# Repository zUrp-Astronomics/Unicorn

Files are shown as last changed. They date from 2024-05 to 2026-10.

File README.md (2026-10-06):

<!-- zurp-readme-header:begin — paste this block once, never again: the poster and the badges update themselves at each build of the site — do not edit it -->
<div align="center">

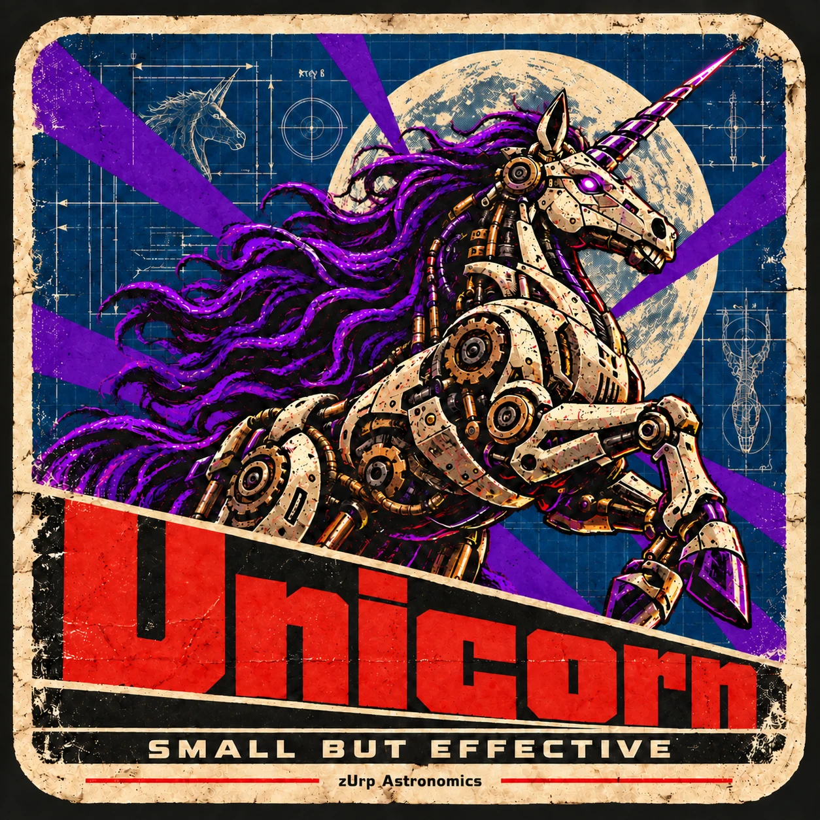
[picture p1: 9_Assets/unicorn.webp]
zUrp Astronomics product poster




</div>

<!-- zurp-readme-header:end -->

# Unicorn — Mount Control Station

# ⚠ Work in Progress — NOT VALIDATED — don't build it ⚠

### A small but efficient controller board for astronomical mounts, featuring TeenAstro Redux

Unicorn is the author's own interpretation of TeenAstro. The files keep the names of the parent
project (`TeenAstro_Redux…`); Unicorn is the zUrp name given to this build.

Visit the main project wiki on [groups.io](https://groups.io/g/TeenAstro/wiki).

The firmware is available on the [TeenAstro GitHub](https://github.com/charleslemaire0/TeenAstro) (support in progress).

## Project details

The source project can be found on [OSHWLab](https://oshwlab.com/lordzurp/teenastro-redux).

### Main board: TeenAstro Redux

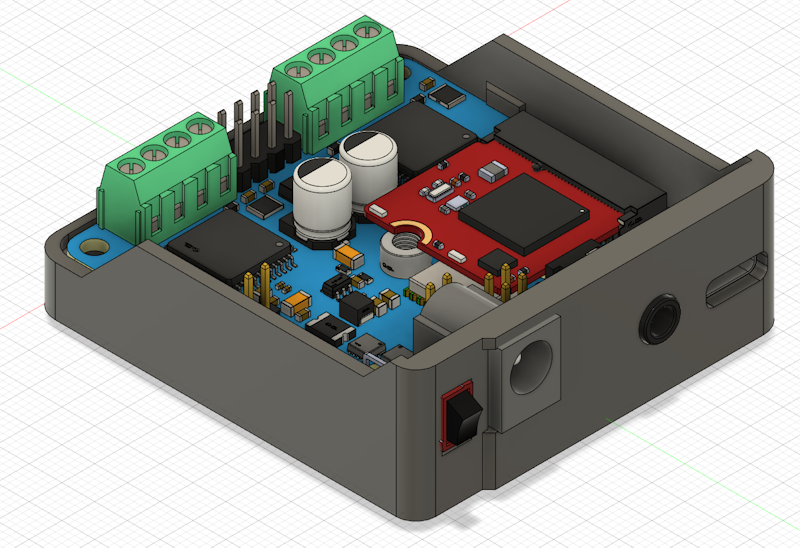
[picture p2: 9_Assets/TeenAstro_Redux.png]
Main board 3D view


#### Specs

* 56 × 52 mm form factor, 60 × 56 × 20 mm 3D-printed case
* 12 to 25 V power input, 3 A max
* Power protection (resettable fuse + reverse polarity)
* ESD protection on the USB and SHC ports
* USB-C connector
* Teensy 4.0 MicroMod
* TMC2660 stepper drivers
* Integrated GNSS
* Encoder support
* No ST4 port

#### PCB views

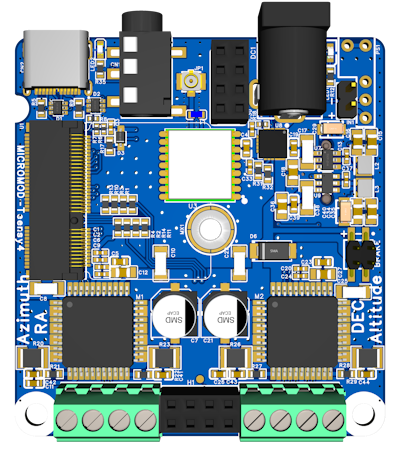
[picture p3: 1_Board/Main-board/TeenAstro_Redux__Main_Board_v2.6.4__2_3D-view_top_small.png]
Main board 3D view, top
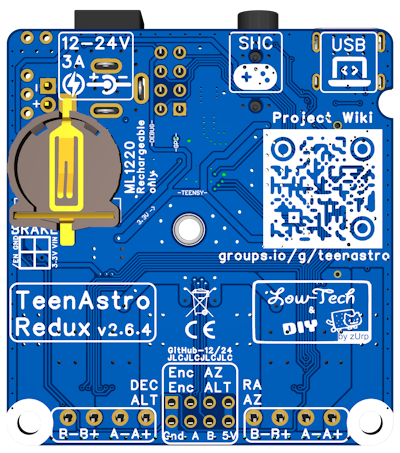
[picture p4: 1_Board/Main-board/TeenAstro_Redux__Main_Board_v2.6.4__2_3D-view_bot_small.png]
Main board 3D view, bottom
 

### Smart Hand Controller (SHC)

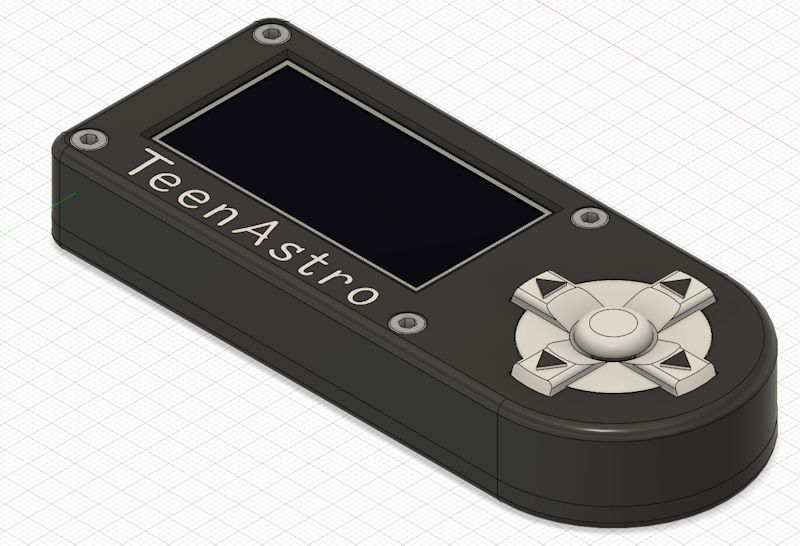
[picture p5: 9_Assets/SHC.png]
SHC 3D view


#### Specs

* 125 × 50 × 20 mm 3D-printed case
* ESP8266 (Wemos D1 mini)
* 2.42" OLED display
* Tactile switches with D-pad style buttons
* Selectable 3.3 V or 5 V power input
* Link through a 4-pin 3.5 mm headphone jack
* No focuser control (planned for later)

#### PCB views

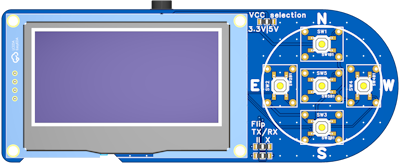
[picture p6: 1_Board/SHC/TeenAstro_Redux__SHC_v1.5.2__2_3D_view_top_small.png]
SHC 3D view, top
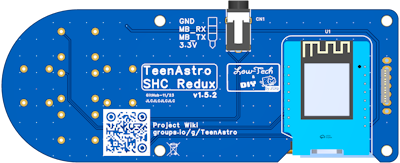
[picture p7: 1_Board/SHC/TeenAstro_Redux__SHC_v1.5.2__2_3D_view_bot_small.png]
SHC 3D view, bottom
 

### Brake module

#### PCB views

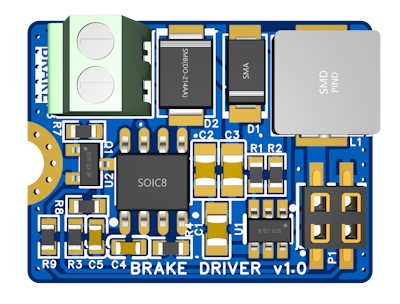
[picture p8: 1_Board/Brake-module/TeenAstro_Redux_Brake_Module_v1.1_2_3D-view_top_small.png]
Brake module 3D view, top
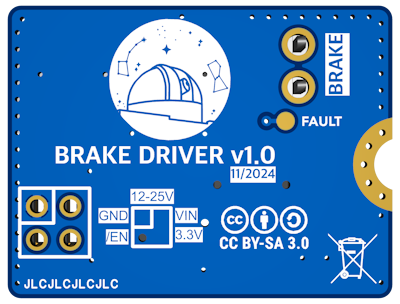
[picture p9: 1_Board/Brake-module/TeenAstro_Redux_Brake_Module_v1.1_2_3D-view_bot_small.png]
Brake module 3D view, bottom
 

## Build instructions

### The fancy way: JLCPCB prototyping service

Open the OSHWLab project in the editor, click "Order PCB", wait a week or two, and enjoy!

The BOM is tuned to minimise assembly costs, so some through-hole components are excluded from
factory assembly: you need to order them and solder them yourself. The good news is that you can
customise the connectors or reuse your own component stock ;)

The through-hole parts are listed in the BOM file, with the "Add into BOM" option set to "No".

### The hard way: do it all yourself

All the necessary files are available in `1_Board/`: complete BOM, Gerber files and pick-and-place.
Choose your PCB manufacturer, order the parts yourself, and level up your soldering skills with a
fully hand-assembled board. Be aware that some components are very small or fine-pitch: manual
assembly should be reserved for advanced, skilled users.

### 3D case

3D models are available to print the cases. The source files (Fusion 360 and STEP, in
`2_Hardware/`) let you customise the cases, while the .3MF files (in `3_3D-Models/`) are ready to
slice and print.

## Repository layout

| folder | contents |
|---|---|
| `0_Datasheets/` | component datasheets |
| `1_Board/` | board manufacturing files: schematics, views, Gerber, BoM, PnP; several boards: one subfolder per board |
| `2_Hardware/` | off-board mechanics: enclosure, parts (STEP), mechanical bill of materials |
| `3_3D-Models/` | ready-to-print files (3MF, STL) |
| `4_Firmware/` | firmware: sources, build, tests |
| `5_App/` | PC / phone applications, configuration tools |
| `9_Assets/` | images for the README and docs; `zurp.yml` showcase sheet and poster, read by the site |

A folder with no purpose for the project is absent.

## Licenses

- Software: GPL-3.0, see [`LICENSE`](LICENSE).
- Hardware: Open Community License (OCL v1.1), see [`LICENSE-HARDWARE`](LICENSE-HARDWARE).

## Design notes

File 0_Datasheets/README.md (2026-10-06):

# 0_Datasheets

Les datasheets des composants utilisés (PDF du fabricant, nom d'origine).

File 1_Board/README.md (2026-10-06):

# 1_Board

Les fichiers de fabrication de la carte, tels que les sort l'outil de CAO.

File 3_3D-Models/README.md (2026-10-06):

# 3_3D-Models

Les fichiers prêts à imprimer, tirés de `2_Hardware/`.

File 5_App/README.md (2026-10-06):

# 5_App

Les applications qui parlent au produit, dont l'outil de configuration TeenAstroConfig.

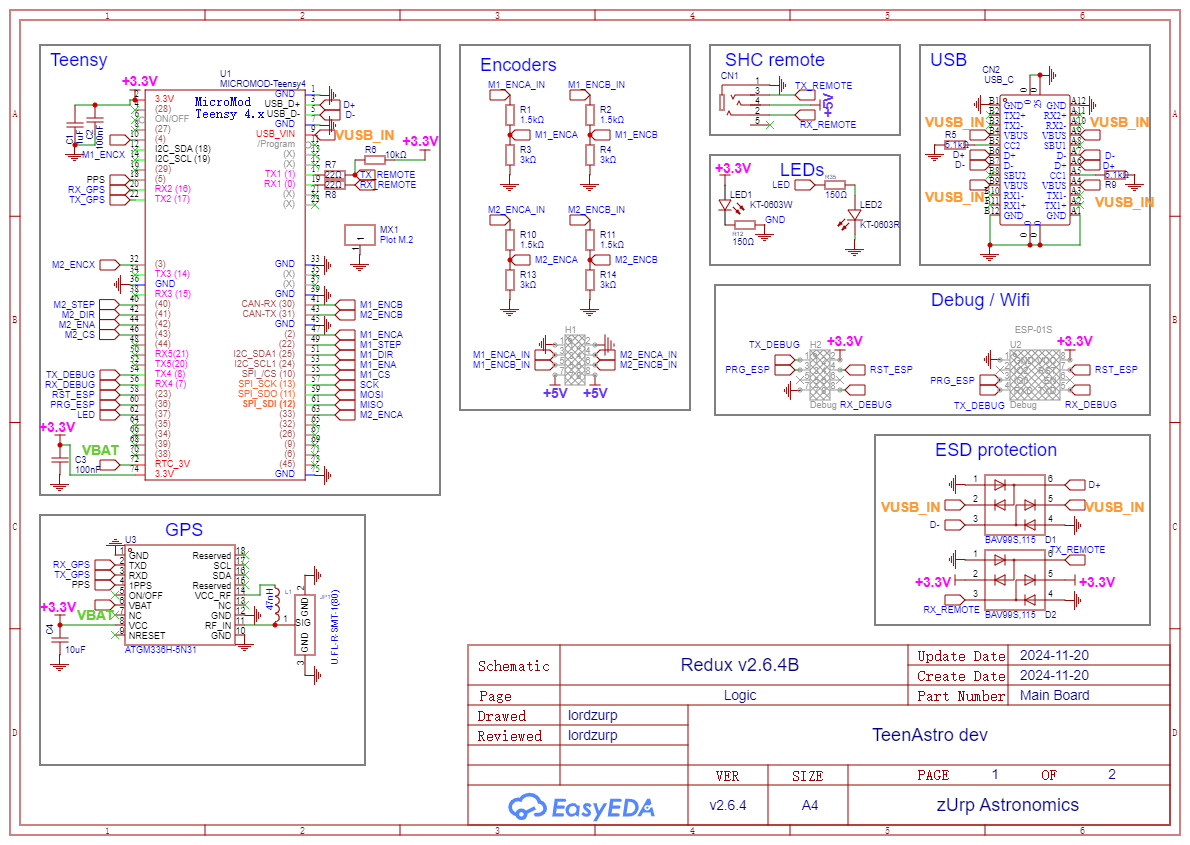
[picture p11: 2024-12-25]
1_Board/Main-board/TeenAstro_Redux__Main_Board_v2.6.4__1_schematics_logic.png

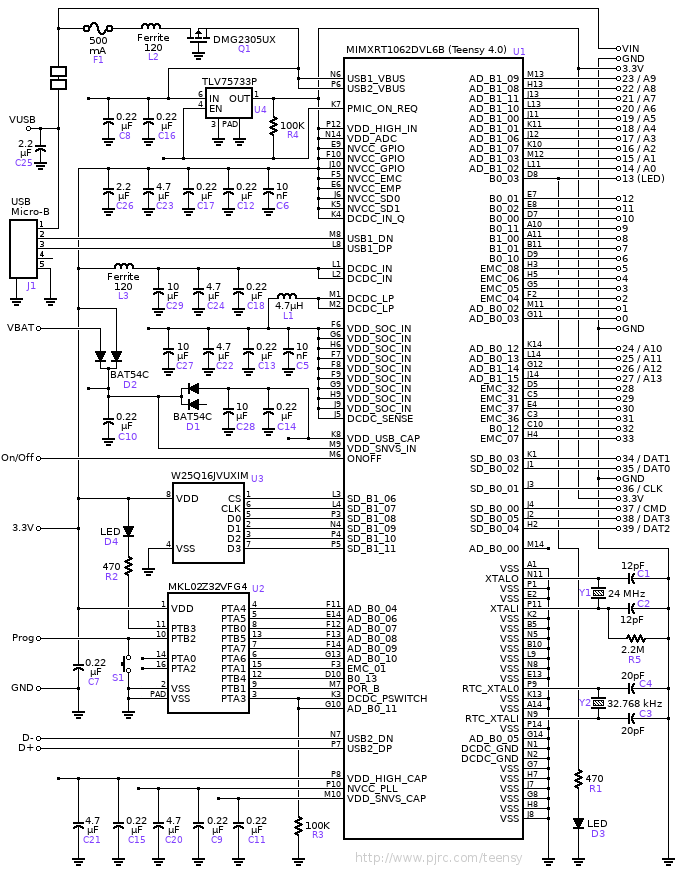
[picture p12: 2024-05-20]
0_Datasheets/#2_MCU/Teensy_4.0_schematic.png

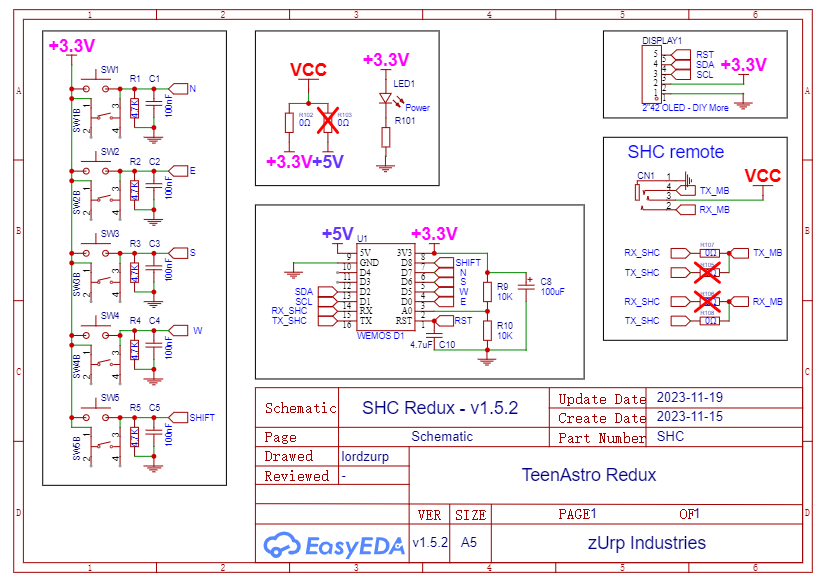
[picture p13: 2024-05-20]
1_Board/SHC/TeenAstro_Redux__SHC_v1.5.2__1_Schematics.png

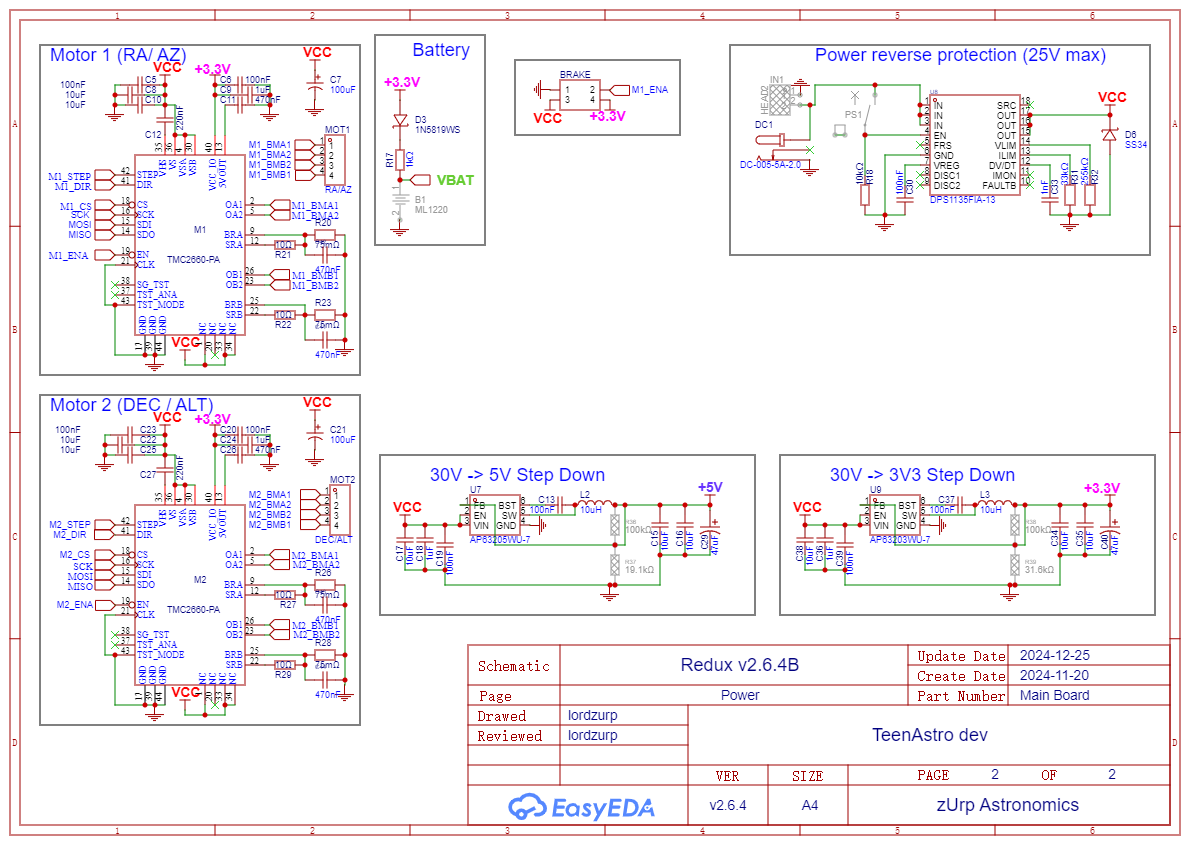
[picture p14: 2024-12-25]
1_Board/Main-board/TeenAstro_Redux__Main_Board_v2.6.4__1_schematics_power.png

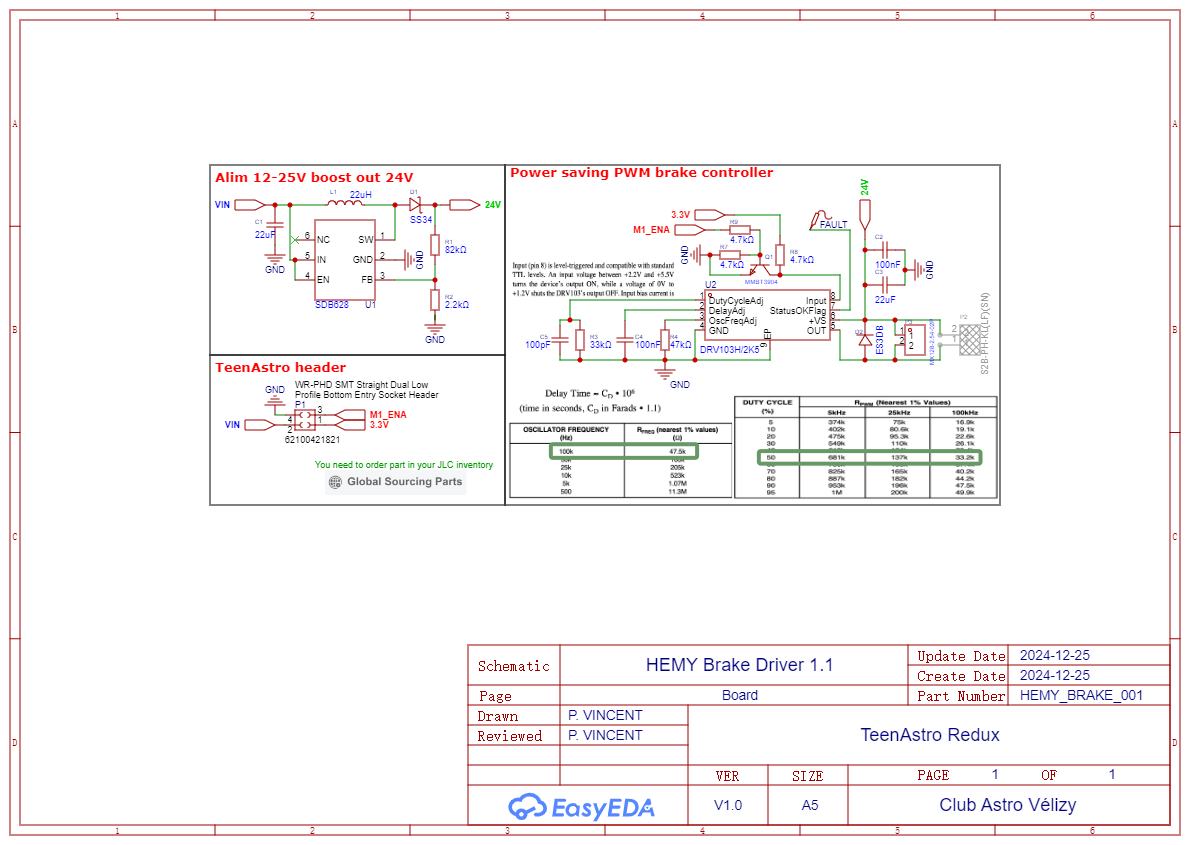
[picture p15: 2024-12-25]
1_Board/Brake-module/TeenAstro_Redux_Brake_Module_v1.1_1_schematics.png

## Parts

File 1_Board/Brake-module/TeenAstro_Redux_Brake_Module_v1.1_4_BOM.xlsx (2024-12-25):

No. | Quantity | Device | Designator | Footprint | Value | Manufacturer Part | Manufacturer | Supplier Part | Supplier | Add into BOM | Name | Primary Category | Secondary Category | JLCPCB Stock | JLCPCB Price | JLCPCB Part Class
1 | 2 | CGA0805X5R226M350MT | C1,C3 | C0805 | 22uF | CGA0805X5R226M350MT | HRE(芯声) | C6119901 | LCSC | yes | 22uF | Capacitors | Multilayer Ceramic Capacitors MLCC - SMD/SMT | 25253 | 0.1214 | Extended Part
2 | 1 | CC0805KRX7R9BB104 | C2 | C0805 | 100nF | CC0805KRX7R9BB104 | YAGEO(国巨) | C49678 | LCSC | yes | 100nF | Capacitors | Multilayer Ceramic Capacitors MLCC - SMD/SMT | 13088190 | 0.0042 | Basic Part
3 | 1 | CC0603KRX7R9BB104 | C4 | C0603 | 100nF | CC0603KRX7R9BB104 | YAGEO(国巨) | C14663 | LCSC | yes | 100nF |  |  | 43585052 | 0.0022 | BasicPart
4 | 1 | CL10C101JB8NNNC | C5 | C0603 | 100pF | CL10C101JB8NNNC | SAMSUNG(三星) | C14858 | LCSC | yes | 100pF |  |  | 5498698 | 0.0022 | Basic Part
5 | 1 | SS34_C8678 | D1 | SMA_L4.3-W2.6-LS5.2-RD |  | SS34 | MDD(辰达半导体) | C8678 | LCSC | yes | SS34 | Diodes | Schottky Diodes | 2849497 | 0.0236 | Basic Part
6 | 1 | ES3DB_C64975 | D2 | SMB_L4.6-W3.6-LS5.3-RD |  | ES3DB | MDD(辰达半导体) | C64975 | LCSC | yes | ES3DB | Diodes | Fast Recovery / High Efficiency Diodes | 13359 | 0.0396 | Extended Part
7 | 1 | Test-Point | FAULT | Test-Point-0.5mm |  |  |  |  |  | yes
8 | 1 | YSPI0630A-220M | L1 | IND-SMD_L7.1-W6.6 | 22uH | YSPI0630A-220M | YJYCOIN(益嘉源) | C497873 | LCSC | yes | 22uH | Inductors, Coils, Chokes | Power Inductors | 8073 | 0.1086 | Extended Part
9 | 1 | 6210XX21821_62100421821_ | P1 | 62100421821 |  |  |  |  |  | yes
10 | 1 | S2B-PH-KL(LF)(SN) | P2 | CONN-TH-2P-P2.00_S2B-PH-KL-LF-SN |  | S2B-PH-KL(LF)(SN) | JST | C160237 | LCSC | no | S2B-PH-KL(LF)(SN) | Connectors | Wire To Board Connector | 4087 | 0.039 | Extended Part
11 | 1 | MX128-2.54-02P-GN01-Cu-Y-A | P3 | CONN-TH_2P-P2.54_MX128-2.54-GN01-02P-CU-Y-A |  | MX128-2.54-02P | MAX(迈旭) | C5188442 | LCSC | yes | MX128-2.54-02P | Connectors | Screw Terminal Blocks | 5238 | 0.1608 | Extended Part
12 | 1 | MMBT3904_C20526 | Q1 | SOT-23-3_L2.9-W1.3-P1.90-LS2.4-BR |  | MMBT3904 | CJ(江苏长电/长晶) | C20526 | LCSC | yes | MMBT3904 | Triode/MOS Tube/Transistor | Bipolar Transistors - BJT | 1710913 | 0.0089 | Basic Part
13 | 1 | 0603WAF8202T5E | R1 | R0603 | 82kΩ | 0603WAF8202T5E | UNI-ROYAL(厚声) | C23254 | LCSC | yes | 82kΩ | Resistors | Chip Resistor - Surface Mount | 453107 | 0.001 | Basic Part
14 | 1 | 0603WAF2201T5E_C4190 | R2 | R0603 | 2.2kΩ | 0603WAF2201T5E | UNI-ROYAL(厚声) | C4190 | LCSC | yes | 2.2kΩ | Resistors | Chip Resistor - Surface Mount | 1557620 | 0.0009 | Basic Part
15 | 1 | 0603WAF3302T5E | R3 | R0603 | 33kΩ | 0603WAF3302T5E | UNI-ROYAL(厚声) | C4216 | LCSC | yes | 33kΩ |  |  | 891407 | 0.001 | Basic Part
16 | 1 | 0603WAF4702T5E | R4 | R0603 | 47kΩ | 0603WAF4702T5E | UNI-ROYAL(厚声) | C25819 | LCSC | yes | 47kΩ | Resistors | Chip Resistor - Surface Mount | 1256019 | 0.0009 | Basic Part
17 | 3 | 0603WAF4701T5E | R7,R8,R9 | R0603 | 4.7kΩ | 0603WAF4701T5E | UNI-ROYAL(厚声) | C23162 | LCSC | yes | 4.7kΩ | Resistors | Chip Resistor - Surface Mount | 7258991 | 0.001 | Basic Part
18 | 1 | SDB628 | U1 | SOT-23-6_L2.9-W1.6-P0.95-LS2.8-BR |  | SDB628 | SHOUDING(首鼎半导体) | C77805 | LCSC | yes | SDB628 | Power Management (PMIC) | DC-DC Converters | 1419 | 0.1797 | Extended Part
19 | 1 | DRV103H/2K5 | U2 | SOIC-8_L4.9-W3.9-P1.27-LS6.0-BL-EP2.3 |  | DRV103H/2K5 | TI(德州仪器) | C544418 | LCSC | yes | DRV103H/2K5 | Motor Driver ICs | Brushed DC Motor Drivers | 43 | 6.018 | Extended Part

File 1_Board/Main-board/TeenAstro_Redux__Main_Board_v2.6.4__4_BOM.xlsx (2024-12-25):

No. | Quantity | Device | Designator | Footprint | Value | Manufacturer Part | Manufacturer | Supplier Part | Supplier | Add into BOM | Name | Primary Category | Secondary Category | JLCPCB Stock | JLCPCB Price | JLCPCB Part Class
1 | 1 | CR1220-2 | B1 | BAT-SMD_CR1220-2 |  | CR1220-2 | Q&J | C70381 | LCSC | no | ML1220 |  |  | 4019 | 0.2067 | Extended Part
2 | 1 | X4621WVS-2x02I-C40D64 | BRAKE | HDR-SMD_4P-P2.00-V-M-R2-C2-S2.0 |  | X4621WVS-2x02I-C40D64 | XKB Connection(中国星坤) | C917607 | LCSC | yes | X4621WVS-2x02I-C40D64 |  |  | 2295 | 0.0438 | Extended Part
3 | 3 | CL05A105KA5NQNC | C1,C9,C24 | C0402 | 1uF | CL05A105KA5NQNC | SAMSUNG(三星) | C52923 | LCSC | yes | 1uF |  |  | 8217185 | 0.0025 | Basic Part
4 | 7 | CL05B104KO5NNNC | C2,C3,C6,C13,C20,C30,C37 | C0402 | 100nF | CL05B104KO5NNNC | SAMSUNG(三星) | C1525 | LCSC | yes | 100nF |  |  | 10654528 | 0.0011 | Basic Part
5 | 1 | GRM188R6YA106MA73D | C4 | C0603 | 10uF | GRM188R6YA106MA73D | muRata(村田) | C194427 | LCSC | yes | 10uF |  |  | 25425 | 0.032 | Extended Part
6 | 4 | CC0603KRX7R9BB104 | C5,C19,C23,C39 | C0603 | 100nF | CC0603KRX7R9BB104 | YAGEO(国巨) | C14663 | LCSC | yes | 100nF |  |  | 43593068 | 0.0022 | Basic Part
7 | 2 | VEJ101M1VTR-0607 | C7,C21 | CAP-SMD_BD6.3-L6.6-W6.6-RD | 100uF | VEJ101M1VTR-0607 | lelon(立隆) | C176666 | LCSC | yes | 100uF |  |  | 8173 | 0.0495 | Extended Part
8 | 6 | CL31A106KBHNNNE | C8,C10,C17,C22,C25,C38 | C1206 | 10uF | CL31A106KBHNNNE | SAMSUNG(三星) | C13585 | LCSC | yes | 10uF |  |  | 1540601 | 0.0293 | Basic Part
9 | 2 | CL10B474KA8NNNC | C11,C26 | C0603 | 470nF | CL10B474KA8NNNC | SAMSUNG(三星) | C1623 | LCSC | yes | 470nF |  |  | 556393 | 0.0061 | Basic Part
10 | 2 | CL21B224KBFNNNE | C12,C27 | C0805 | 220nF | CL21B224KBFNNNE | SAMSUNG(三星) | C5378 | LCSC | yes | 220nF |  |  | 395589 | 0.0092 | Basic Part
11 | 4 | CL21A106KAYNNNE_C15850 | C15,C16,C34,C35 | C0805 | 10uF | CL21A106KAYNNNE | SAMSUNG(三星) | C15850 | LCSC | yes | 10uF |  |  | 3145192 | 0.0089 | Basic Part
12 | 2 | CL21B105KBFNNNE | C18,C36 | C0805 | 1uF | CL21B105KBFNNNE | SAMSUNG(三星) | C28323 | LCSC | yes | 1uF |  |  | 3311283 | 0.008 | Basic Part
13 | 2 | CA45-A-10V-47uF-M | C29,C40 | CAP-SMD_L3.2-W1.6 | 47uF | CA45-A-10V-47uF-M | CEC(振华新云) | C688949 | LCSC | yes | 47uF |  |  | 8002 | 0.1284 | Extended Part
14 | 1 | 0402B102K500NT | C33 | C0402 | 1nF | 0402B102K500NT | FH(风华) | C1523 | LCSC | yes | 1nF |  |  | 1893324 | 0.001 | Basic Part
15 | 4 | CL10A474KB8NNNC | C41,C42,C43,C44 | C0603 | 470nF | CL10A474KB8NNNC | SAMSUNG(三星) | C170149 | LCSC | yes | 470nF | Capacitors | Multilayer Ceramic Capacitors MLCC - SMD/SMT | 31860 | 0.0147 | Extended Part
16 | 1 | PJ-327E-SMT | CN1 | AUDIO-SMD_PJ-327E-SMT |  | PJ-327E-SMT | XKB Connectivity(中国星坤) | C319105 | LCSC | yes | PJ-327E-SMT | Connectors | Audio Connectors | 34 | 0.1353 | Extended Part
17 | 1 | USB_C | CN2 | USB-C-SMD_TYPE-C-USB-18 |  | 105450-0101 | MOLEX | C134092 | LCSC | yes | USB_C |  |  | 8158 | 0.6615 | Extended Part
18 | 2 | BAV99S,115 | D1,D2 | SOT-363_L2.0-W1.3-P0.65-LS2.1-TL |  | BAV99S,115 | Nexperia(安世) | C96225 | LCSC | yes | BAV99S,115 | Diodes | Switching Diode | 39427 | 0.0326 | Extended Part
19 | 1 | 1N5819WS_C191023 | D3 | SOD-323_L1.8-W1.3-LS2.5-RD |  | 1N5819WS | Hottech(合科泰) | C191023 | LCSC | yes | 1N5819WS |  |  | 723257 | 0.0079 | Basic Part
20 | 1 | SS34_C8678 | D6 | SMA_L4.3-W2.6-LS5.2-RD |  | SS34 | MDD(辰达半导体) | C8678 | LCSC | yes | SS34 | Diodes | Schottky Diodes | 2849507 | 0.0236 | Basic Part
21 | 1 | DC-005-5A-2.0 | DC1 | DC-IN-TH_DC-005-5A-2.0 |  | DC-005-5A-2.0 | XKB Connection(中国星坤) | C381116 | LCSC | yes | DC-005-5A-2.0 |  |  | 2183 | 0.1904 | Extended Part
22 | 2 | DS1023-2*4SF11 | H1,H2 | HDR-TH_8P-P2.54-V-F-R2-C4-S2.54 |  | DS1023-2*4SF11 | CONNFLY | C92271 | LCSC | no | Debug,DS1023-2*4SF11 |  |  | 5806 | 0.0828 | Extended Part
23 | 1 | HEAD2 | IN1 | HDR-TH_2P-P2.54-V-M |  | HEAD2 |  | C9900010030 | LCSC | no | HEAD2 |  |  | 0 |  | Extended Part
24 | 1 | U.FL-R-SMT-1(80)_C88374 | JP1 | RF-SMD_FRF05002-JSS103M |  | U.FL-R-SMT-1(80) | HRS(广濑) | C88374 | LCSC | yes | U.FL-R-SMT-1(80) | Connectors | RF Connectors / Coaxial Connectors | 41593 | 0.0743
25 | 1 | LQW18AN47NJ00D | L1 | IND-SMD_L1.6-W0.8-1 | 47nH | LQW18AN47NJ00D | muRata(村田) | C98077 | LCSC | yes | 47nH | Inductors/Coils/Transformers | Power Inductors | 5428 | 0.0299 | Extended Part
26 | 2 | SWPA252012S100MT | L2,L3 | IND-SMD_L2.5-W2.0_SWPA252012S | 10uH | SWPA252012S100MT | Sunlord(顺络) | C37428 | LCSC | yes | 10uH |  |  | 13438 | 0.0485 | Extended Part
27 | 1 | KT-0603W | LED1 | LED0603-R-RD_WHITE |  | KT-0603W | KENTO | C2290 | LCSC | yes | KT-0603W |  |  | 1058322 | 0.0091 | Basic Part
28 | 1 | KT-0603R | LED2 | LED0603-RD |  | KT-0603R | KENTO | C2286 | LCSC | yes | KT-0603R |  |  | 4329736 | 0.005 | Basic Part
29 | 2 | TMC2660-PA | M1,M2 | PQFP44_WITH_PADS |  | TMC2660C-PA-T | TMC2660C-PA-T | C2927052 | LCSC | yes | TMC2660-PA |  |  | 489 | 5.5635
30 | 2 | DB125-3.5-4P-GN-S | MOT1,MOT2 | CONN-TH_DB125-3.5-4P-GN |  | DB125-3.5-4P-GN-S | DIBO(地博电气) | C2757925 | LCSC | yes | DEC/ALT,RA/AZ | Connectors | Screw terminal | 14677 | 0.3146 | Extended Part
31 | 1 | SMTSO3030CTJ | MX1 | SMD_BD5.6-D4.1 |  | SMTSO3030CTJ | Sinhoo(雄和远景) | C2915308 | LCSC | yes | Plot M.2 | Hardware Fasteners/Seals | Nuts | 5705 | 0.047 | Extended Part
32 | 1 | Power_Switch | PS1 | Power_switch |  | 4US1R102M7RN | MULTICOMP PRO | 1550227 | Farnell | no |  |  |  | 0
33 | 4 | 0603WAF1501T5E | R1,R2,R10,R11 | R0603 | 1.5kΩ | 0603WAF1501T5E | UNI-ROYAL(厚声) | C22843 | LCSC | yes | 1.5kΩ | Resistors | Chip Resistor - Surface Mount | 1888119 | 0.001 | BasicPart
34 | 4 | 0603WAF3001T5E | R3,R4,R13,R14 | R0603 | 3kΩ | 0603WAF3001T5E | UNI-ROYAL(厚声) | C4211 | LCSC | yes | 3kΩ | Resistors | Chip Resistor - Surface Mount | 1289777 | 0.001 | BasicPart
35 | 2 | 0603WAF5101T5E | R5,R9 | R0603 | 5.1kΩ | 0603WAF5101T5E | UNI-ROYAL(厚声) | C23186 | LCSC | yes | 5.1kΩ |  |  | 5365015 | 0.0009 | Basic Part
36 | 2 | 0402WGF1002TCE | R6,R18 | R0402 | 10kΩ | 0402WGF1002TCE | UNI-ROYAL(厚声) | C25744 | LCSC | yes | 10kΩ |  |  | 15571380 | 0.0005 | Basic Part
37 | 2 | 0402WGF220JTCE | R7,R8 | R0402 | 22Ω | 0402WGF220JTCE | UNI-ROYAL(厚声) | C25092 | LCSC | yes | 22Ω |  |  | 2581213 | 0.0005 | Basic Part
38 | 2 | 0603WAF1500T5E | R12,R35 | R0603 | 150Ω | 0603WAF1500T5E | UNI-ROYAL(厚声) | C22808 | LCSC | yes | 150Ω | Resistors | Chip Resistor - Surface Mount | 1195069 | 0.001 | Basic Part
39 | 1 | 0603WAF1001T5E | R17 | R0603 | 1kΩ | 0603WAF1001T5E | UNI-ROYAL(厚声) | C21190 | LCSC | yes | 1kΩ |  |  | 28780492 | 0.0009 | Basic Part
40 | 4 | RTT12R075FTP | R20,R23,R26,R28 | R1210 | 75mΩ | RTT12R075FTP | RALEC(旺诠) | C333258 | LCSC | yes | 75mΩ | Resistors | Chip Resistor - Surface Mount | 391 | 0.0165 | Extended Part
41 | 4 | 0603WAF100JT5E | R21,R22,R27,R29 | R0603 | 10Ω | 0603WAF100JT5E | UNI-ROYAL(厚声) | C22859 | LCSC | yes | 10Ω |  |  | 2512458 | 0.0009 | Basic Part
42 | 1 | 0603WAF3302T5E | R31 | R0603 | 33kΩ | 0603WAF3302T5E | UNI-ROYAL(厚声) | C4216 | LCSC | yes | 33kΩ |  |  | 891407 | 0.001 | Basic Part
43 | 1 | RC0603FR-07255KL_C295887 | R32 | R0603 | 255kΩ | RC0603FR-07255KL | YAGEO(国巨) | C295887 | LCSC | yes | 255kΩ |  |  | 5430 | 0.0011 | Extended Part
44 | 2 | 0402WGF1003TCE | R36,R38 | R0402 | 100kΩ | 0402WGF1003TCE | UNI-ROYAL(厚声) | C25741 | LCSC | no | 100kΩ | Resistors | Chip Resistor - Surface Mount | 4362025 | 0.0005 | Basic Part
45 | 1 | 0603WAF1912T5E | R37 | R0603 | 19.1kΩ | 0603WAF1912T5E | UNI-ROYAL(厚声) | C22897 | LCSC | no | 19.1kΩ | Resistors | Chip Resistor - Surface Mount | 48643 | 0.0009 | Extended Part
46 | 1 | 0603WAF3162T5E | R39 | R0603 | 31.6kΩ | 0603WAF3162T5E | UNI-ROYAL(厚声) | C25967 | LCSC | no | 31.6kΩ | Resistors | Chip Resistor - Surface Mount | 162239 | 0.001 | Extended Part
47 | 1 | MICROMOD-Teensy4 | U1 | M.2-CONNECTOR-E |  | AS0BC21-S48BE-7H | Foxconn | C2761457 | LCSC | yes | MICROMOD-Teensy4 |  |  | 5876 | 0.852
48 | 1 | ESP-01 | U2 | WIFIM-TH_8P-L24.7-W14.4-P2.54 | 2.4GHz | ESP-01S | Ai-Thinker(安信可) | C503581 | LCSC | no | Debug | IoT/Communication Modules | WiFi Modules | 82 | 2.2695 | ExtendedPart
49 | 1 | ATGM336H-5N31 | U3 | GPSM-SMD_ATGM336H-TR |  | ATGM336H-5N31 | 杭州中科微 | C90770 | LCSC | yes | ATGM336H-5N31 | IoT/Communication Modules | Satellite Positioning Modules | 3617 | 2.988 | Extended Part
50 | 1 | AP63205WU-7 | U7 | TSOT-23-6_L2.9-W1.6-P0.95-LS2.8-BL |  | AP63205WU-7 | DIODES(美台) | C2071056 | LCSC | yes | AP63205WU-7 | Power Management (PMIC) | DC-DC Converters | 23412 | 0.3405 | Extended Part
51 | 1 | DPS1135FIA-13 | U8 | QFN-17_L4.0-W4.0-P0.50-TL-EP |  | DPS1135FIA-13 | DIODES(美台) | C2150216 | LCSC | yes | DPS1135FIA-13 | Power Supply Chip | Power Distribution Switches | 3479 | 1.1895 | Extended Part
52 | 1 | AP63203WU-7 | U9 | TSOT-26_L2.9-W1.6-P0.95-LS2.8-BL |  | AP63203WU-7 | DIODES(美台) | C780769 | LCSC | yes | AP63203WU-7 |  |  | 16543 | 0.3025 | Extended Part

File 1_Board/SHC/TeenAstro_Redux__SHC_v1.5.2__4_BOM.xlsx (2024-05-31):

No. | Quantity | Device | Designator | Footprint | Value | Manufacturer Part | Manufacturer | Supplier Part | Supplier | Add into BOM | Name | Primary Category | Secondary Category | JLCPCB Stock | JLCPCB Price | JLCPCB Part Class
1 | 5 | CC0603KRX7R9BB104 | C1,C2,C3,C4,C5 | C_0603 |  | CC0603KRX7R9BB104 | YAGEO | C14663 | LCSC | yes | 100nF |  |  | 43333683 | 0.014 | Basic
2 | 1 | TAJB107K006RNJ | C8 | CAP-SMD_L3.5-W2.8 |  | TAJB107K006RNJ | AVX | C16133 | LCSC | yes | 100uF |  |  | 359967 | 0.99 | Basic
3 | 1 | CL10A475KO8NNNC | C10 | C0603 | 4.7uF | CL10A475KO8NNNC | SAMSUNG(三星) | C19666 | LCSC | yes | 4.7uF | Capacitors | Multilayer Ceramic Capacitors MLCC - SMD/SMT | 2931171 | 0.0599 | BasicPart
4 | 1 | PJ-322环保 | CN1 | AUDIO-TH_HOOYA_PJ-322 |  | PJ-322环保 | HOOYA(皓宇电子) | C2939185 | LCSC | no | PJ-322环保 | Connectors | Audio Connectors | 5026 | 1.186 | ExtendedPart
5 | 1 | 2.54mm 1*5P Header | DISPLAY1 | HDR-TH_5P-P2.54-V |  | 2.54mm1*5PHeader | ReliaPro | C50951 | LCSC | no | 2&quot;42 OLED - DIY More |  |  | 0 | 0.095
6 | 1 | KT-0603R | LED1 | LED0603-RD |  | KT-0603R | KENTO | C2286 | LCSC | yes | KT-0603R |  |  | 2784512 | 0.0352 | Basic Part
7 | 5 | 0603WAF4701T5E | R1,R2,R3,R4,R5 | R_0603 |  | 0603WAF4701T5E | UniOhm | C23162 | LCSC | yes | 4.7K |  |  | 11036892 | 0.00648 | Basic
8 | 2 | 0603WAF1002T5E | R9,R10 | R_0603 |  | 0603WAF1002T5E | UniOhm | C25804 | LCSC | yes | 10K |  |  | 15865827 | 0.00564 | Basic
9 | 1 | 0603WAF4700T5E | R101 | R0603 | 470Ω | 0603WAF4700T5E | UNI-ROYAL(厚声) | C23179 | LCSC | yes | 470Ω |  |  | 2642829 | 0.00656 | Basic Part
10 | 6 | 0805W8F0000T5E_C17477 | R102,R103,R105,R106,R107,R108 | R0805 | 0Ω | 0805W8F0000T5E | UNI-ROYAL(厚声) | C17477 | LCSC | no,yes | 0Ω | Resistors | Chip Resistor - Surface Mount | 4221224 | 0.0108 | Basic Part
11 | 5 | TL3300CF260Q | SW1,SW2,SW3,SW4,SW5 | SWITCH_NAVI |  | TL3300CF260Q | E-SWITCH | 612-TL3300CF260Q | Mouser | no | Momentary Switch |  |  | 0
12 | 5 | TS-1187A-B-A-B | SW1B1,SW2B1,SW3B1,SW4B1,SW5B1 | SW-SMD_4P-L5.1-W5.1-P3.70-LS6.5-TL-2 |  | TS-1187A-B-A-B | XKB Connectivity(中国星坤) | C318884 | LCSC | yes | TS-1187A-B-A-B |  |  | 607990 | 0.109 | Basic Part
13 | 1 | WEMOS D1 | U1 | WEMOS D1 |  |  |  |  |  | yes | WEMOS D1

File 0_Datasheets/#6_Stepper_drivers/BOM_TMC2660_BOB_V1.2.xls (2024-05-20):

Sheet: Part List Report
 | BOM |  | <Parameter Title not found>
 | Project: | TMC2660_BOB
 | Version: | 1.2
 | Date: | 18.07.2017
# | Quantity | MPN | Comment | Designator | Footprint | Description | Note | MF
1 | 1 | MC0603X474K160CT | 470nF/16V/10% | C1 | C0603 | Ceramic capacitor |  | Multicomp
2 | 3 | MC0603F104M500CT | 100nF/50V/20% | C2, C3, C7 | C0603 | Ceramic capacitor |  | Multicomp
3 | 2 | MC0603B103K500C | 10nF/50V/10% | C5, C6 | C0603 | Ceramic capacitor |  | MULTICOMP
4 | 4 | GRM31CC8YA106KA12L | 10uF/35V/10% | C8, C9, C10, C11 | C1206 | Ceramic capacitor |  | MURATA
5 | 1 | LTST-C191TBKT-5A | LED, Blue, SMD, 20mA, 2.8V, 465 nm | D1 | LED_0603 | LED, Blue, SMD, 20mA, 2.8V, 465 nm |  | Lite-On
6 | 1 | TMC2660-PA | TMC2660 | IC1 | TMC26x_PQFP44_0.8_10X10_TMC236 | coolStep™ driver with Step/Dir Interface and SPI, up to 30V, internal MOSFET for up to 4 A, PQFP-44 |  | TRINAMIC
7 | 2 | MCWR06X10R0FTL | 10R / 1% | R1, R2 | R0603 | SMD Chip Resistor, Thick Film, 10 ohm, 50 V, 0603 [1608 Metric], 100 mW, ± 1%, MCWR Series |  | Multicomp
8 | 2 | ERJ8BWFR100V | 100mR / 1W / 1% | R3, R4 | R1206 | SMD Current Sense Resistor, 0.1 ohm, 1 W, 1206 [3216 Metric], ± 1%, ERJ8B Series |  | PANASONIC ELECTRONIC COMPONENTS
9 | 1 | MC0063W060311K | 1k | R5 | R0603 | 1 kohm, 50 V, 0603 [1608 Metric], 63 mW, ± 1%, MC Series |  | MULTICOMP
Approved |  |  | Notes |  |  |  |  | 26

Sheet: Project Information
Project Full Path | C:\Users\Urmo\Desktop\SYSTEEM\MEGA\PCB_PROJECTS\Trinamic\4BreakoutBoards\TMC2660\V1.2\TMC2660_BOB_V1_2.PrjPcb
Project Filename | TMC2660_BOB_V1_2.PrjPcb
Variant Name | TMC2660_BOB_V1.1
Data-Source Filename | TMC2660_BOB_V1_2.PrjPcb
Data-Source Full Path | C:\Users\Urmo\Desktop\SYSTEEM\MEGA\PCB_PROJECTS\Trinamic\4BreakoutBoards\TMC2660\V1.2\TMC2660_BOB_V1_2.PrjPcb
Title | <Parameter Title not found>
Total Quantity | 26
Report Time | 21:03:06
Report Date | 18.07.2017
Report Date & Tine | 18.07.2017 21:03:06
Output Name | BOM
Output Type | BOM_PartType
Output Generator Name | BOM
Output Generator Description | Bill of Materials

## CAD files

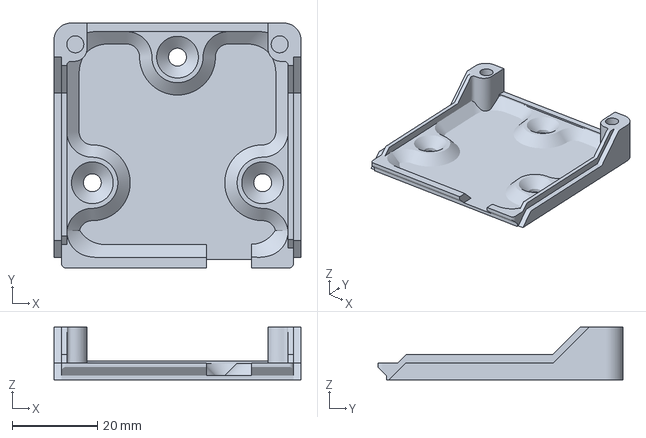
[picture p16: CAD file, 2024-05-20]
3_3D-Models/MainBoard_case_bot.3mf
58.0 x 57.5 x 12.4 mm

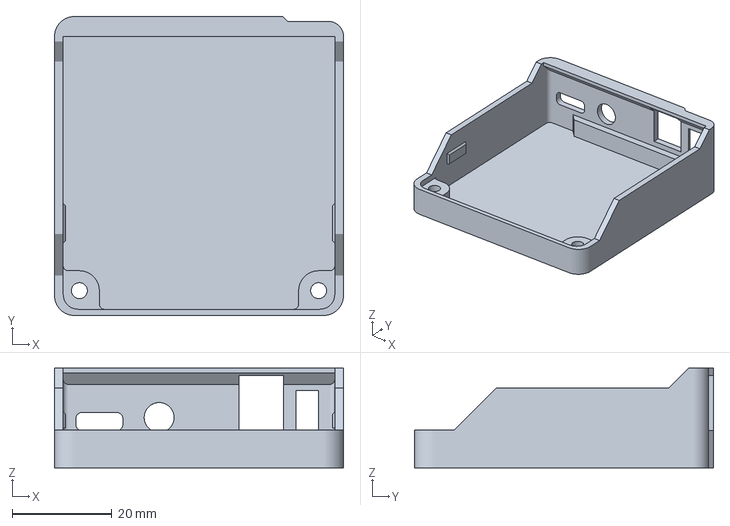
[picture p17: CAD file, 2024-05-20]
3_3D-Models/MainBoard_case_top.3mf
58.0 x 60.0 x 20.0 mm

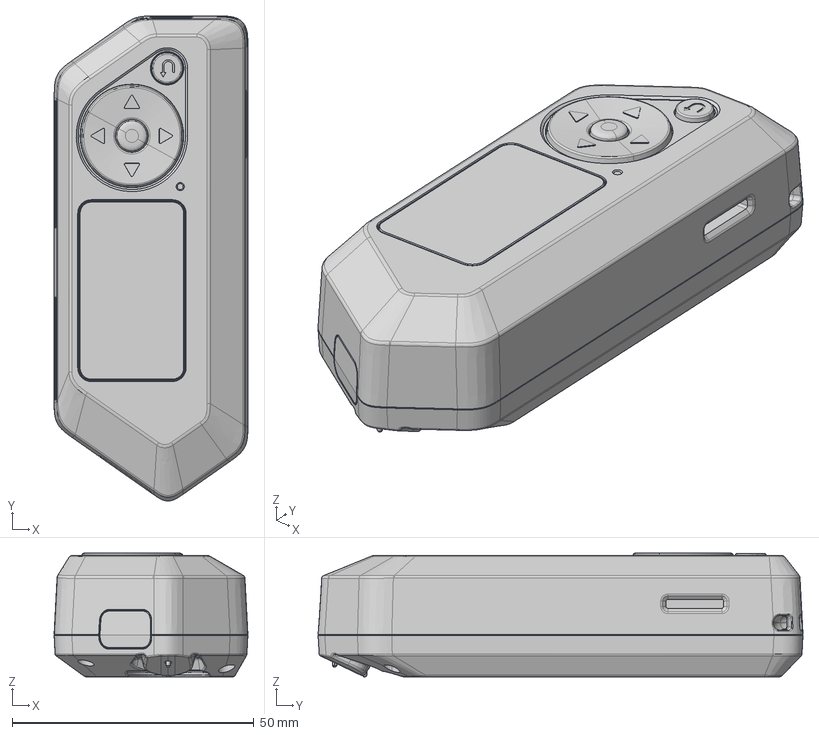
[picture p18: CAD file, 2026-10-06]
0_Datasheets/#8_Modules/Flipper_zero/flipper-zero-body-3d.stp
40.1 x 100.3 x 25.6 mm

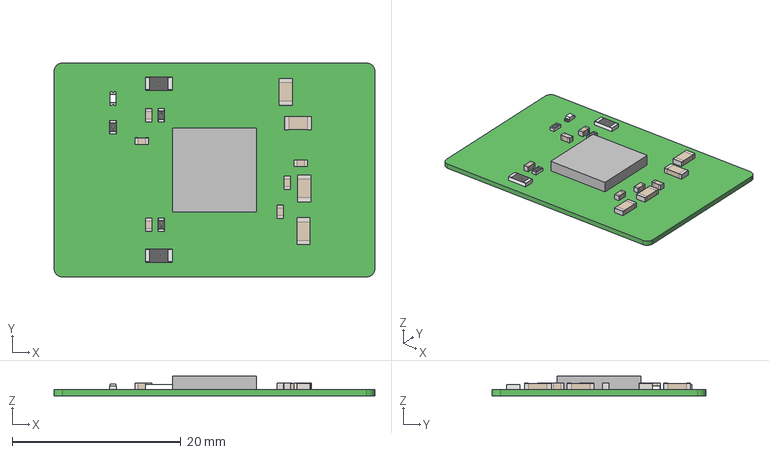
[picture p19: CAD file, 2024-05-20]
0_Datasheets/#8_Modules/TMC2660-BOB_3D_Files_Layout_Data_V1.2/3D_TMC2660_BOB_V1.2.step
38.1 x 25.4 x 2.32 mm

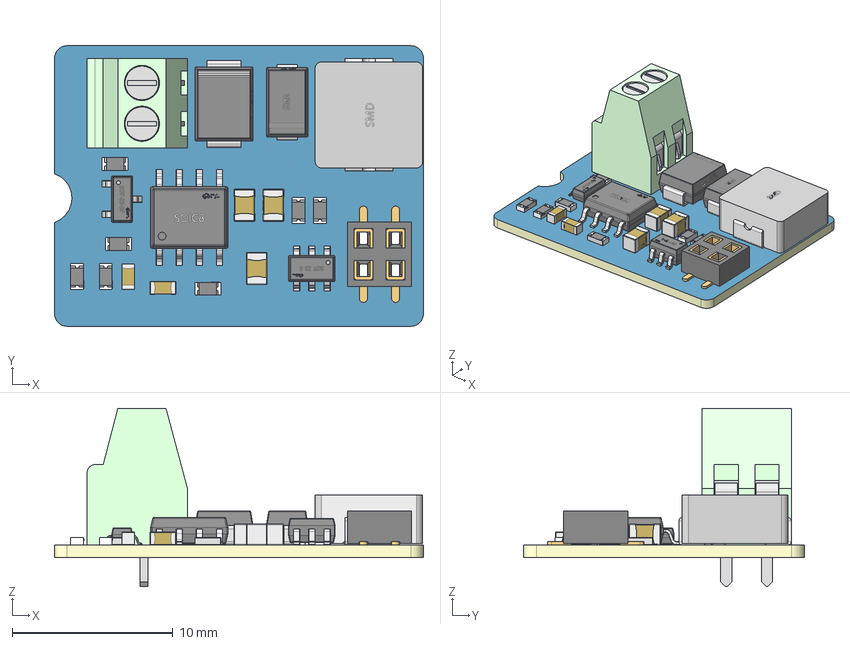
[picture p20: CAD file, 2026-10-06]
1_Board/Brake-module/TeenAstro_Redux_Brake_Module_v1.1_2_3D-view.step
23.0 x 17.5 x 11.1 mm
TopTrack
BottomTrack
Board

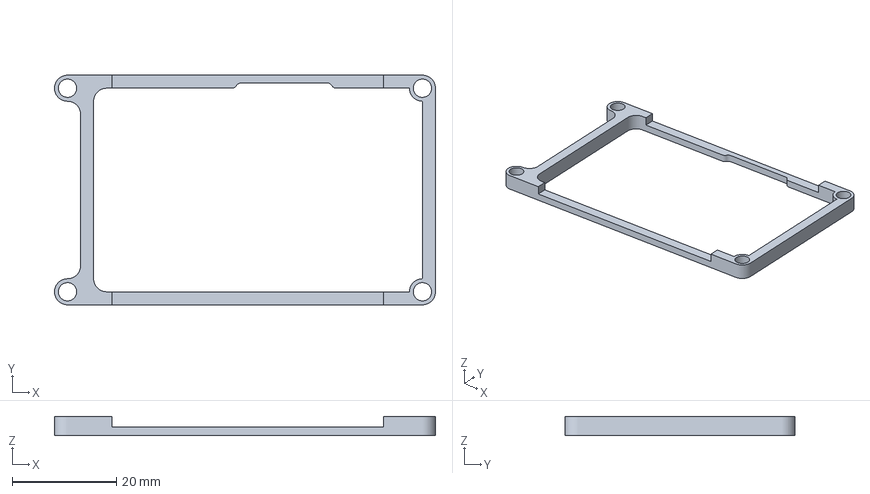
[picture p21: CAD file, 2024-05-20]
3_3D-Models/SHC_spacer_screen.3mf
73.0 x 44.0 x 3.70 mm

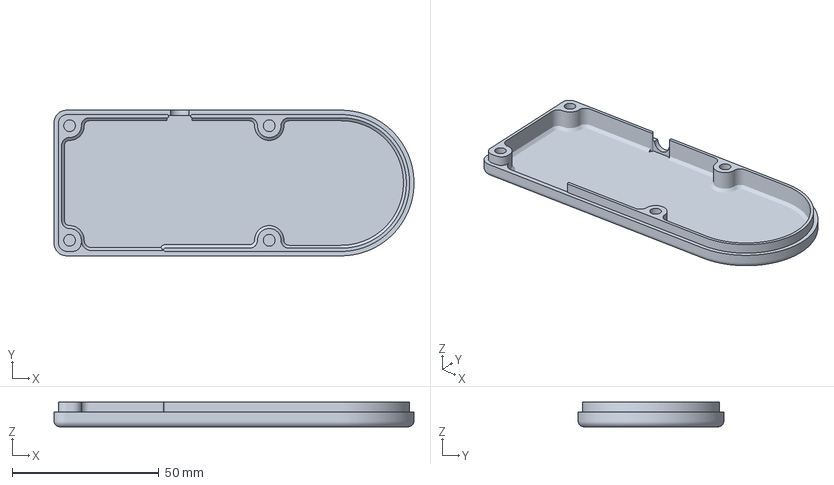
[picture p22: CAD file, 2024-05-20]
3_3D-Models/SHC_case_bot.3mf
122.6 x 49.6 x 8.40 mm

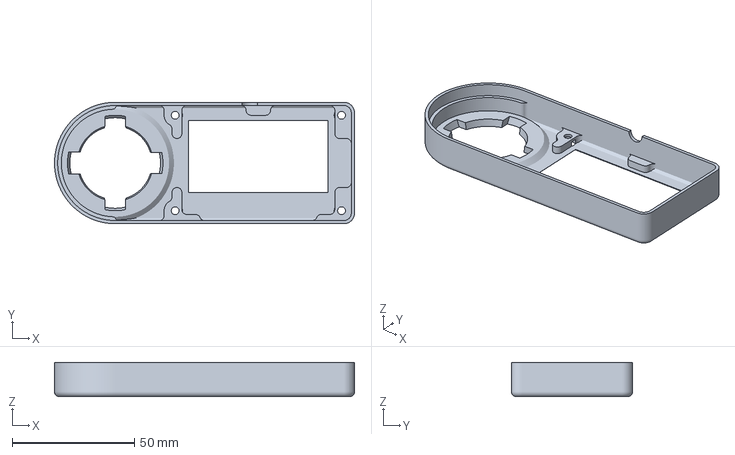
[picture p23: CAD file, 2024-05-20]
3_3D-Models/SHC_case_top.3mf
122.6 x 49.6 x 14.0 mm

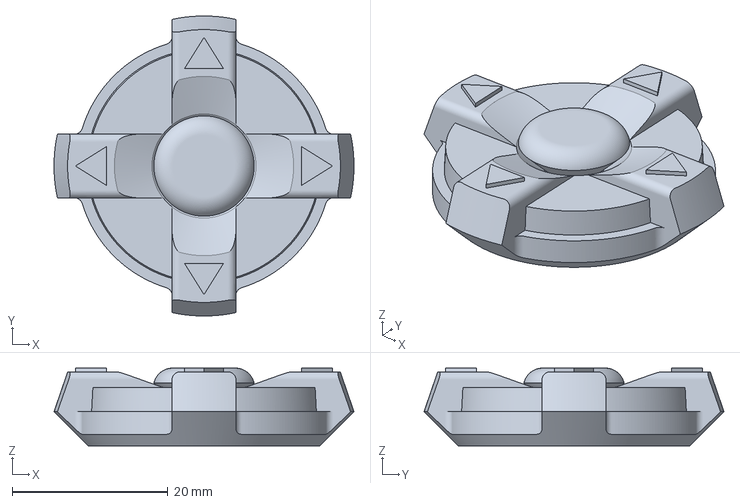
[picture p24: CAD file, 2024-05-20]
3_3D-Models/SHC_LaCroix.3mf
38.5 x 38.5 x 10.0 mm

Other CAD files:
0_Datasheets/#8_Modules/Flipper_zero/flipper-zero-body-3d.stl
2_Hardware/TeenAstro-Redux.f3d

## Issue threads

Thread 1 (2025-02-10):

Incorrect footprint for U1 on main board

danb35, 2025-02-10:
The locating holes for U1, the Foxconn m.2 connector for the Teensy, are too small to allow placement of that part.  Using the board design on oshwlab, the holes are 0.8 and 0.55mm in diameter; the footprint in the datasheet (below) calls for 1.6 and 1.1mm:

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

I've updated a copy in my own EasyEDA account, but I don't know of a way to do the equivalent of a PR on OSHWLab.

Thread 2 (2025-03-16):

SHC Housing models - port for cable doesn't match PCB

danb35, 2025-03-16:
The 3D models for the SHC housing include an opening for the 3.5mm TRRS jack to connect it to the mainboard.  However, that opening doesn't match the location of CN1 on the PCB layout--by eye, I'd call it about 6mm too far to the right (see photo attached).

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

danb35, 2025-03-16:
After downloading the Fusion 360 model and exporting these two parts, the opening for the port matches the PCB layout.  It seems to just be the `.3mf` files in the repo that have this issue.

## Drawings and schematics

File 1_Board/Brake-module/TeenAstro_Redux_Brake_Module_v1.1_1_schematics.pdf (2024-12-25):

## Power saving PWM brake controller Alim 12-25V boost out 24V

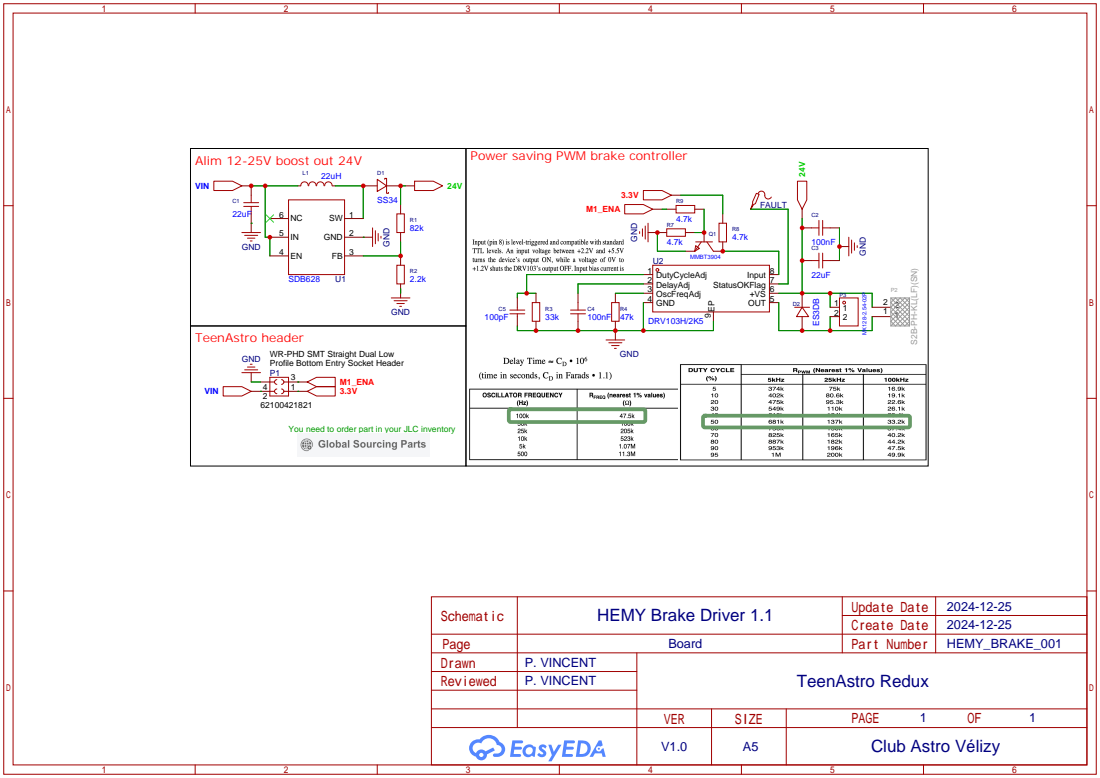
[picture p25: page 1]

You need to order part in your JLC inventory

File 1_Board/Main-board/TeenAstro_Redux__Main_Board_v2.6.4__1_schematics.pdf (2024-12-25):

# Teensy

+3.3V

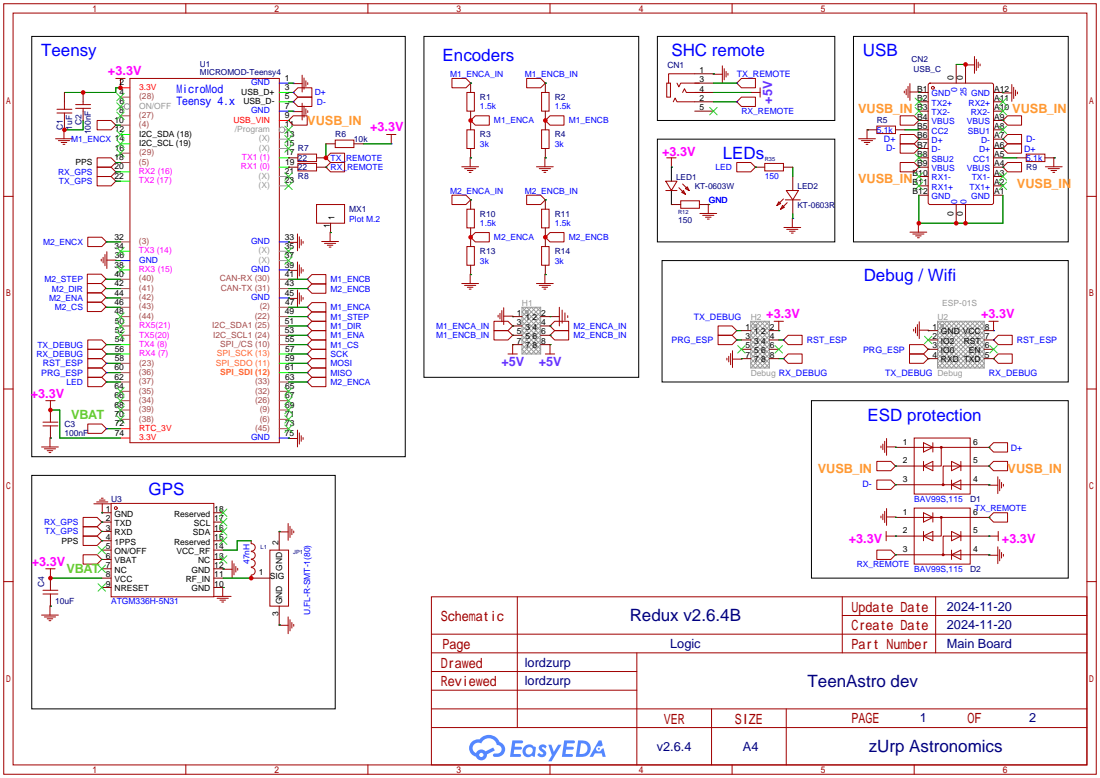
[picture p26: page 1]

# Motor 1 (RA/ AZ)

# VCC +3.3V NC

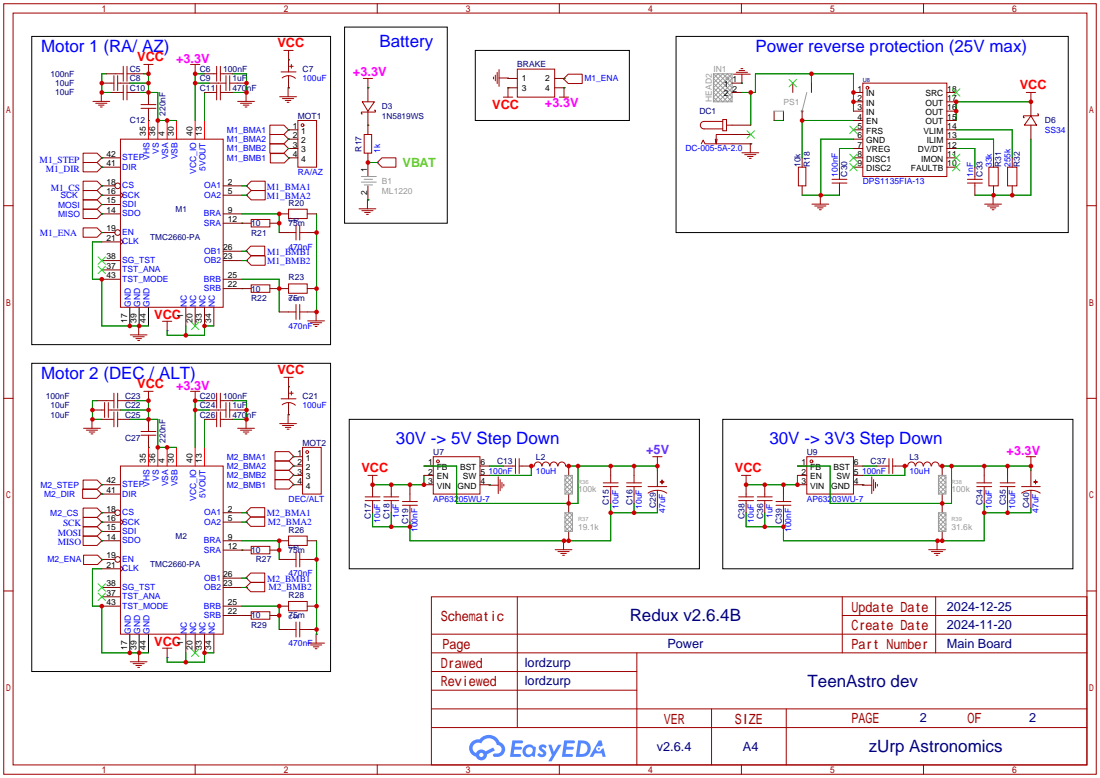
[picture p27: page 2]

C9 | 1uF
C11 | 470nF

FAULTB 10 IMON 11 DV/DT 12 ILIM 13 VLIM 14 OUT 15 OUT 16 OUT 17 SRC 18

C24 | 1uF
C26 | 470nF

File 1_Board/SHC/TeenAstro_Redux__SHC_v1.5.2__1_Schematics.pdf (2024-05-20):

+3.3V

+3.3V

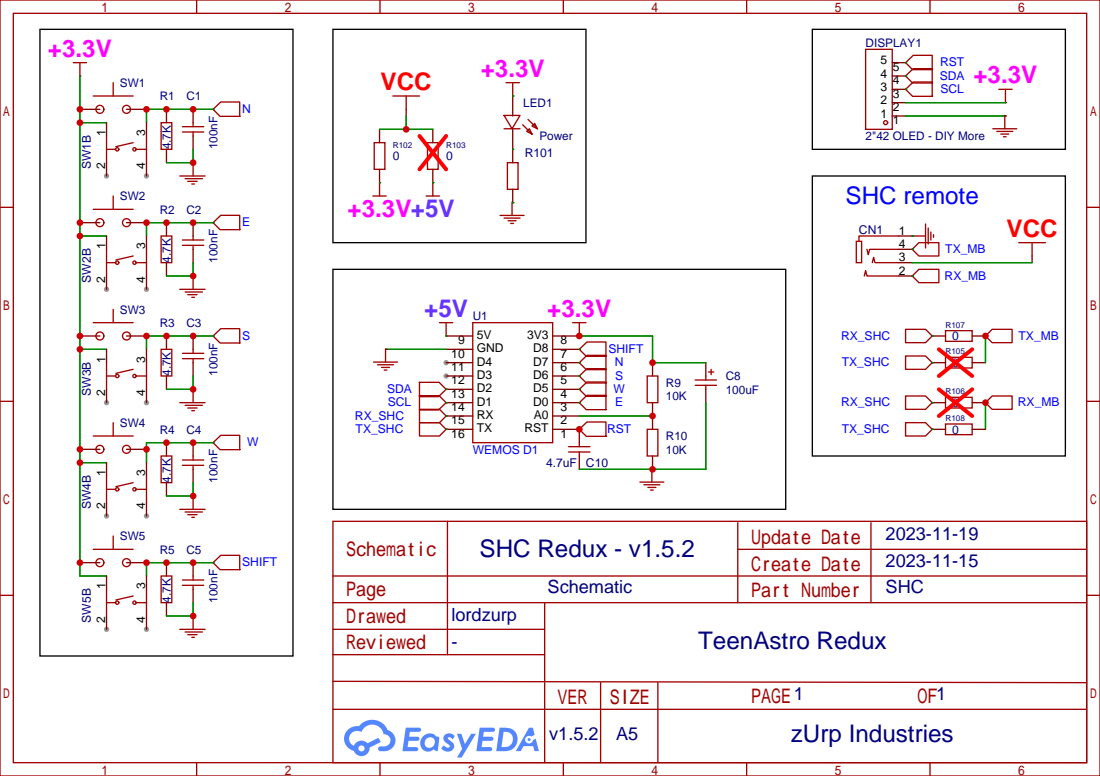
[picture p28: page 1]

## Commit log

2024-05-20 pop repo
    [3D_TMC2660_BOB_V1.2.step, BOM_TMC2660_BOB_V1.2.xls, MainBoard_case_bot.3mf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]
2024-05-31 update repo
    [TeenAstro_Redux__Main_Board_v2.6.4__4_BOM.xlsx, TeenAstro_Redux__Main_Board_v2.6.4__5_PnP.xlsx]
2024-05-31 fix BOM
    [TeenAstro_Redux__Main_Board_v2.6.4__4_BOM.xlsx]
2024-05-31 update BOM
    [TeenAstro_Redux__Main_Board_v2.6.4__4_BOM.xlsx]
2024-06-02 board size adjusting
    [TeenAstro_Redux__Main_Board_v2.6.4__5_PnP.xlsx]
2024-12-25 bump v2.6.4 + brake module
    [MainBoard_case_bot.3mf, MainBoard_case_top.3mf, SHC_LaCroix.3mf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]
2026-10-06 chore(import-externe): déclaration de criticité (.lcars.json)
2026-10-06 ci(import): rail CI du depot (.gitea/workflows)
2026-10-06 chore(layout): mise au gabarit zUrp du dépôt Unicorn (#3)
    - Rangement par git mv, fichiers intacts : 0_Datasheets, 1_Board/{Main-board,SHC,Brake-module},
    2_Hardware (f3d + STEP), 3_3D-Models (3mf), 4_Firmware, 9_Assets.
    - Doublon supprimé : 0_Datasheets/#8_Modules/ATGM336H (1).pdf (= #3_Peripheriques/ATGM336H-5N31.pdf).
    - README de dossier du gabarit 0_…9_ ; nommage réécrit dans 1_Board, 2_Hardware, 3_3D-Models
    (noms d'origine gardés), 9_Assets sans « modèle commenté ».
    - Vitrine : 9_Assets/unicorn.png, 9_Assets/zurp.yml (second paragraphe corrigé : ni ST4 ni
    Bluetooth), .github/workflows/zurp-site.yml à l'identique.
    - README racine réécrit en anglais, liens d'images ve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
    [3D_TMC2660_BOB_V1.2.step, BOM_TMC2660_BOB_V1.2.xls, MainBoard_case_bot.3mf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]
2026-10-06 fix(vitrine): zurp.yml ne nomme plus ST4 ni Bluetooth, même en commentaire (#3)
    Le commentaire d'en-tête qui documente la correction citait les deux fonctions retirées ;
    le critère porte sur le fichier entier. Il dit désormais seulement qu'un paragraphe a été corrigé.
    Claude-Session: https://claude.ai/code/session_017kJVPtJwJWMVJ8LfmZwbAn
2026-10-06 docs(readme): affiche locale 9_Assets/unicorn.png dans le bloc d'en-tête (#7)
    Seule la valeur de src change sur la ligne de l'affiche ; href, alt, width,
    badges et marqueurs zurp-readme-header restent tels quels (décision humaine).
    Claude-Session: https://claude.ai/code/session_016eyjAggQaHaTT4h1PtLV7E
2026-10-06 chore(repo): mise à jour dépôt produit zUrp v2 (#11)
    - LICENSE-HARDWARE (OCL v1.1) ajouté à la racine, LICENSE GPL-3.0 inchangé
    - .github/workflows/zurp-site.yml remplacé par le workflow du doc § 5
    - TeenAstroConfig*.exe déplacés de 4_Firmware/ vers 5_App/
    - 6_Driver/, 7_Docs/, 8_References/ et le modèle PRODUIT-vX.Y_0-README.txt retirés
    - README de dossier réduits à un titre et une phrase
    - README racine : en-têtes Date/Status/Referenced by, badge licence et
    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
2026-10-06 feat(assets): affiche Unicorn en WebP — 9_Assets/unicorn.webp remplace unicorn.png (#12)
    Copie octet pour octet de matiere/unicorn.webp (sha256 289ce850…0f9c, 1254 × 1254).
    zurp.yml : poster: unicorn.webp. README : src de l'affiche locale -> 9_Assets/unicorn.webp.
    Claude-Session: https://claude.ai/code/session_01AP7oV2LBRZQsMoaQf7JdMF
